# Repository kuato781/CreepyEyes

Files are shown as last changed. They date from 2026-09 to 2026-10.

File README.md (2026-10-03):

# CreepyEyes

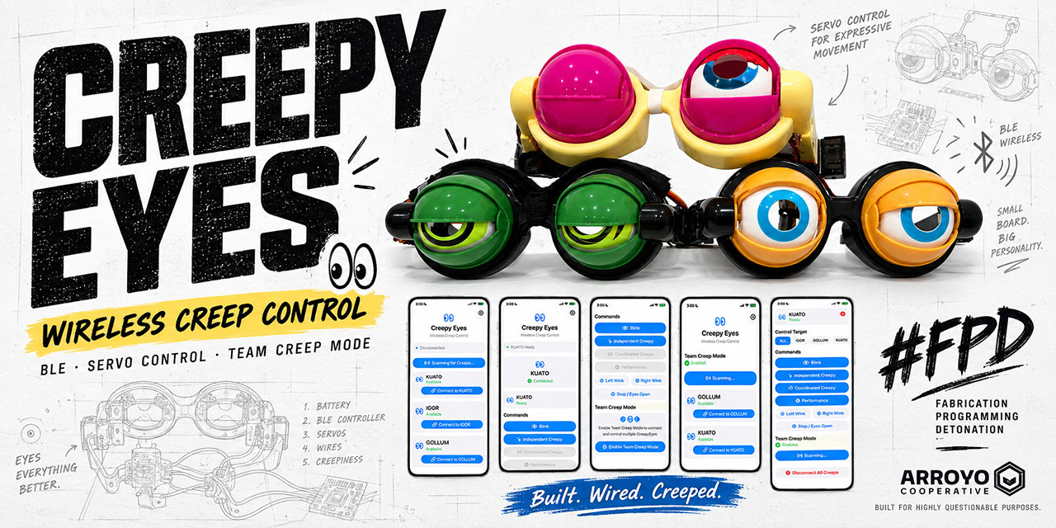
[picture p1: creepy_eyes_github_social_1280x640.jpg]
CreepyEyes


Native iPhone BLE control for servo-driven **Creepy Eyes** glasses.

Built by Arroyo Cooperative for highly questionable purposes. 👀

CreepyEyes combines:

- a native SwiftUI iPhone app
- BLE-connected Seeed Studio XIAO ESP32-C3 controllers
- independently servo-driven eyelids
- per-creep calibration
- single-device and multi-device control
- synchronized pseudo-random movement
- app-orchestrated Performance mode
- a compact wearable hardware build

## Current status

The app is functionally complete through **V3 Team Creep Mode**.

Named Creeps:

- `KUATO`
- `IGOR`
- `GOLLUM`
- `FESTER`
- `LURCH`

The fleet is being standardized on the newer compact hardware architecture documented in [hardware/README.md](hardware/README.md): smaller sub-micro servos, direct-solder servo wiring, formed heat-shrink loom, and the improved ball-bearing linkage clamp.

The compact hardware revision is a substantial packaging cleanup over the original build:

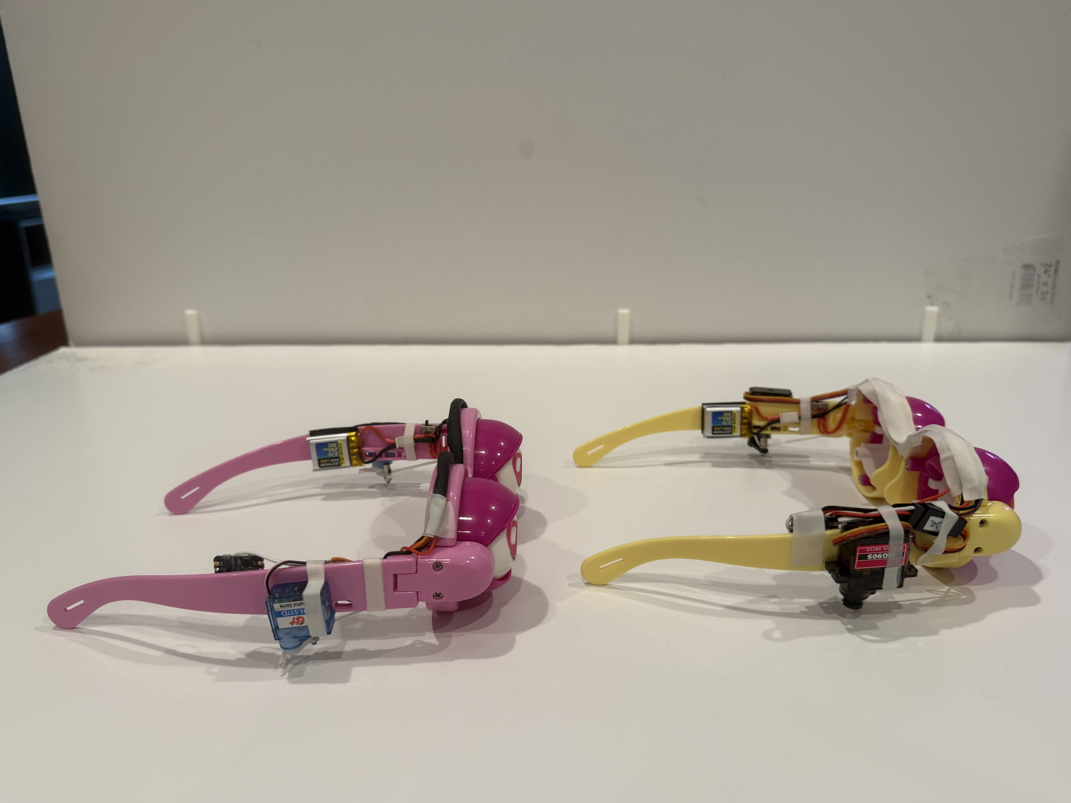
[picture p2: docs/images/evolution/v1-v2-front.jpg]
CreepyEyes hardware evolution


Additional comparison views are available in [`docs/images/evolution/`](docs/images/evolution/), and a short fleet demo is in [`CreepsInMotion.mp4`](docs/images/media/CreepsInMotion.mp4).

## What the app does

The iPhone app:

- scans for nearby CreepyEyes devices
- connects securely over BLE
- displays each creep by its advertised name
- controls one creep by default
- enables multi-device control through **Team Creep Mode**
- stores motion settings locally on the iPhone
- routes commands to one creep or the whole connected fleet
- generates shared seeds for Coordinated Creepy behavior
- orchestrates Performance mode
- safely stops Creeps before disconnecting

Supported behaviors:

- **Blink**
- **Left Wink**
- **Right Wink**
- **Independent Creepy**
- **Coordinated Creepy**
- **Performance**
- **Stop / Eyes Open**

## Team Creep Mode

The app intentionally starts as a simple single-Creep controller.

After one Creep is connected, the user can explicitly enable **Team Creep Mode** for that app session. That reveals `Scan for More Creeps` and allows multiple hardware units to be connected.

With multiple Creeps connected, the app can target:

- `ALL`
- any individual connected creep

Fleet-only behaviors such as Coordinated Creepy and Performance become available when multiple Creeps are connected and `ALL` is selected.

Team Creep Mode is session-only and does not use a password, subscription, license key, or in-app purchase.

## Independent Creepy

Each creep generates its own random movement sequence and speed range, producing intentionally uncoordinated motion across the fleet.

## Coordinated Creepy

The iPhone generates one random seed and sends the same seed and behavior parameters to participating Creeps.

The firmware uses a deterministic pseudo-random generator, so Creeps receiving the same seed follow the same action/speed sequence.

## Performance mode

Performance is orchestrated by the iPhone app rather than hard-coded into the firmware.

Default sequence:

```text
Left Wink
→ Right Wink
→ Blink
→ Independent Creepy
→ Coordinated Creepy
```

The first four phases use the configurable Performance duration. Coordinated Creepy remains active until another command is sent.

`Stop / Eyes Open` interrupts the sequence immediately.

## Factory defaults

```text
Wink Interval               3.0 sec
Wink Speed                  1.0x
Blink Interval              3.0 sec
Blink Speed                 1.0x
Creepy Transition Interval  1.0 sec
Creepy Minimum Speed        0.5x
Creepy Maximum Speed        1.5x
Performance Action Duration 10 sec
```

## BLE protocol

Service UUID:

```text
4fafc201-1fb5-459e-8fcc-c5c9c331914b
```

Characteristic UUID:

```text
beb5483e-36e1-4688-b7f5-ea07361b26a8
```

Commands:

```text
L:<speed>
R:<speed>
B:<transition interval>:<speed>
I:<transition interval>:<minimum speed>:<maximum speed>
C:<transition interval>:<minimum speed>:<maximum speed>:<seed>
S
```

Where:

- `L` = one Left Wink
- `R` = one Right Wink
- `B` = repeating Blink
- `I` = Independent Creepy
- `C` = Coordinated Creepy
- `S` = Stop / Eyes Open

## Hardware orientation convention

**LEFT and RIGHT are defined from the wearer's perspective.**

```text
D4 = wearer's LEFT eye
D5 = wearer's RIGHT eye
```

This convention is used in current firmware, calibration, wiring, and build documentation.

## Hardware build

The current preferred hardware build is documented here:

- [Hardware build guide](hardware/README.md)
- [BOM and tools](hardware/BOM.md)
- [Textual wiring reference](hardware/WIRING.md)

The repository also includes the glasses assembly/calibration fixture and the current 3-slot sliding-lid travel/storage case:

```text
stl-bambu-3mf/
├── creepy-glass-holder.3mf
├── creepy-glass-holder.stl
├── CreepyEyes-3Slot-Box.3mf
├── CreepyEyes_3Slot_Box_BASE_70mm.stl
├── CreepyEyes_3Slot_Box_LID_70mm.stl
├── CreepyEyes_Lid_Overlay_NORMAL.svg
└── CreepyEyes_Lid_Overlay_MIRRORED.svg
```

The case holds three folded Creeps in separate bays and uses the CreepyEyes SVG as a merged lid overlay:

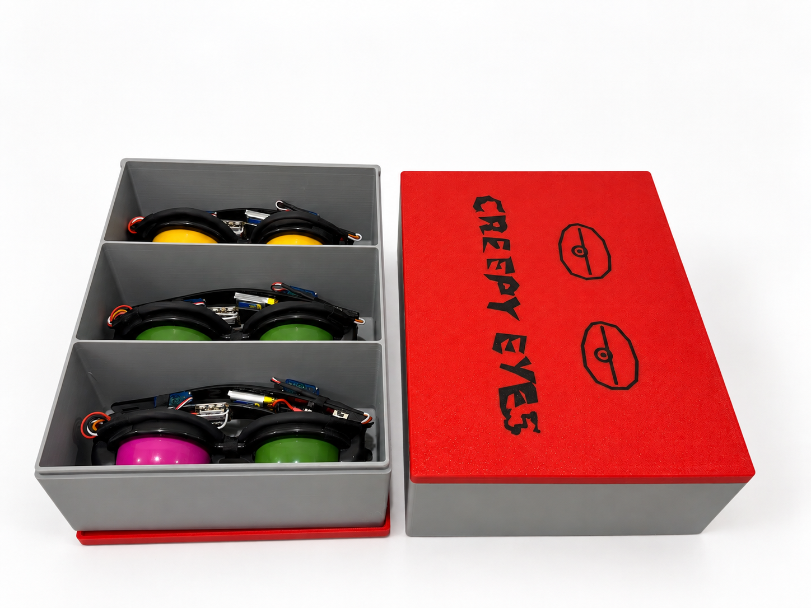
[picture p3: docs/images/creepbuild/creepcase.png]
CreepyEyes 3-slot travel case


## Firmware

The firmware lives under:

```text
firmware/
├── README.md
├── CreepyEyes/
│   ├── CreepyEyes.ino
│   └── secrets.example.h
└── CreepyEyesCalibration/
    └── CreepyEyesCalibration.ino
```

See [firmware/README.md](firmware/README.md) for Arduino setup, calibration, flashing, BLE protocol, and local secrets.

## Local secrets

Production firmware uses a local `secrets.h`:

```cpp
#pragma once
#define CREEP_NAME "KUATO"
#define FLEET_PASSCODE 123456
```

The real fleet passcode must remain local. `secrets.h` is excluded by `.gitignore`; only `secrets.example.h` belongs in source control.

## iPhone app architecture

### `BLEManager.swift`

Owns scanning, connections, characteristic discovery, per-device command channels, command transmission, safe disconnect, and multi-creep BLE state.

### `ContentView.swift`

Owns UI and orchestration: Team Creep Mode, target selection, motion settings, Performance sequencing, and Coordinated Creepy seed generation.

The app sends semantic behavior commands rather than raw servo positions.

## Design philosophy

Firmware owns:

- servo positions and calibration
- motion timing and interpolation
- blink/wink/Creepy behaviors
- safe stop behavior

The iPhone app owns:

- user settings
- connection/target selection
- Team Creep Mode
- fleet orchestration
- Performance sequencing
- coordinated seed generation

## License and disclaimer

See [LICENSE](LICENSE) and [DISCLAIMER.md](DISCLAIMER.md).

CreepyEyes is a hobbyist wearable-electronics project involving LiPo batteries, custom wiring, moving mechanisms, and modified novelty glasses. Build and use it accordingly.

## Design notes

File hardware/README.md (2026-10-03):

# CreepyEyes Hardware Build

This is the current hardware build guide for CreepyEyes.

It reflects the newer compact build developed while assembling FESTER: smaller sub-micro servos, direct-soldered servo wiring, a formed heat-shrink wiring loom, and a 2.5 mm ball-bearing clamp inside the pushrod connector.

> [!WARNING]
> This is not a beginner electronics project. You should already be comfortable with RC servos, small-electronics soldering and wire splicing, multimeter use, LiPo battery handling, flashing firmware to a microcontroller, and basic small-model modification and mechanical fitment.

The exact brands linked in [BOM.md](BOM.md) are what were used during development. Equivalent parts and tools are fine unless a dimension or electrical requirement is specifically called out.

## Build architecture

Each pair of glasses uses:

- 2 sub-micro servos driving the original eyelid mechanisms
- Seeed Studio XIAO ESP32-C3
- 1S 3.7 V 250 mAh LiPo
- DC-DC boost converter configured for approximately 5 V servo power
- 470 µF / 10 V capacitor across the boosted servo rail
- physical power switch
- BT2.0 battery connection
- direct-soldered servo wiring
- heat-shrink-formed loom routed across the frame
- pushrod/linkage connectors clamping the original nylon pull string

The controller and boost board are distributed along the temples rather than stacked.

## Orientation convention

**LEFT and RIGHT are now defined from the wearer's perspective.**

```text
Wearer's LEFT eye  -> D4
Wearer's RIGHT eye -> D5
```

That convention is used in the calibration sketch, production firmware, wiring documentation, and app behavior.

## Before touching electronics

Mechanically inspect the donor glasses first.

Both eyelids should open and close freely before servo installation. If one eye drags or does not fully open, fix or replace the mechanical eye assembly before calibration. A sticky donor mechanism can otherwise look like a servo, linkage, or firmware problem later.

Also test both servos on a servo tester before installing them.

## Servo preparation

The compact build uses GH-S37D-class sub-micro servos rather than the larger MG90S-style servos used in earlier builds.

The smaller servos reduce the side profile significantly and already use thin lead wire that works well with the direct-solder harness.

Optional cleanup:

- trim unused servo mounting ears to reduce bulk
- clean the cut edge carefully without cutting into the case seam

### Servo arm and linkage connector

The supplied servo arms have enough material for the existing pushrod connector.

1. Choose an arm long enough to provide easy access to the connector set screw while still clearing the frame.
2. Enlarge the servo-arm hole to approximately **2.15 mm** so the connector's smooth shoulder can rotate freely.
3. Enlarge the connector's nylon-cord hole to approximately **2 mm** as needed. A diamond Dremel bit works well on the hardened connector material; use high tool speed with low feed pressure.
4. Use the connector nut without a washer.
5. Apply only a small amount of green Loctite to the first 3-5 screw threads. Do not flood Loctite onto the plastic servo arm.
6. Tighten only enough to retain the connector while allowing the smooth shoulder to rotate freely.

The goal is **free rotation and clearance**, not simply making every hole larger.

## Nylon pull-string clamp: current method

The connector's 3 mm set screw does not reach far enough to clamp the thin nylon pull string by itself.

An earlier build used a short piece of 3D-printer filament as a spacer. That worked, but depending on how the filament slug landed, it could damage or cut the nylon string.

The current method uses a **2.5 mm steel ball bearing** inside the connector under the set screw.

The ball:

- fits the connector cleanly
- allows the set screw to clamp the nylon securely
- creates a smooth, repeatable contact surface
- did not leave visible bite marks on the nylon during destructive/reassembly testing

This supersedes the filament-slug method.

## Servo mounting

The working geometry is:

- servos on the outside of the temple frame
- output gear facing rearward
- outer edge aligned near the former stock string-guide edge
- servo body approximately 2 mm below the bottom of the frame

Use servo tape for initial positioning and mechanical testing before committing the final attachment.

Center each servo with a tester before installing the horn. Install the arm near 90 degrees inward and tension the nylon so the eyelid is roughly half closed at servo center. Final endpoints are established later with the calibration sketch.

### Build photos

**Servo installation / fixture setup**

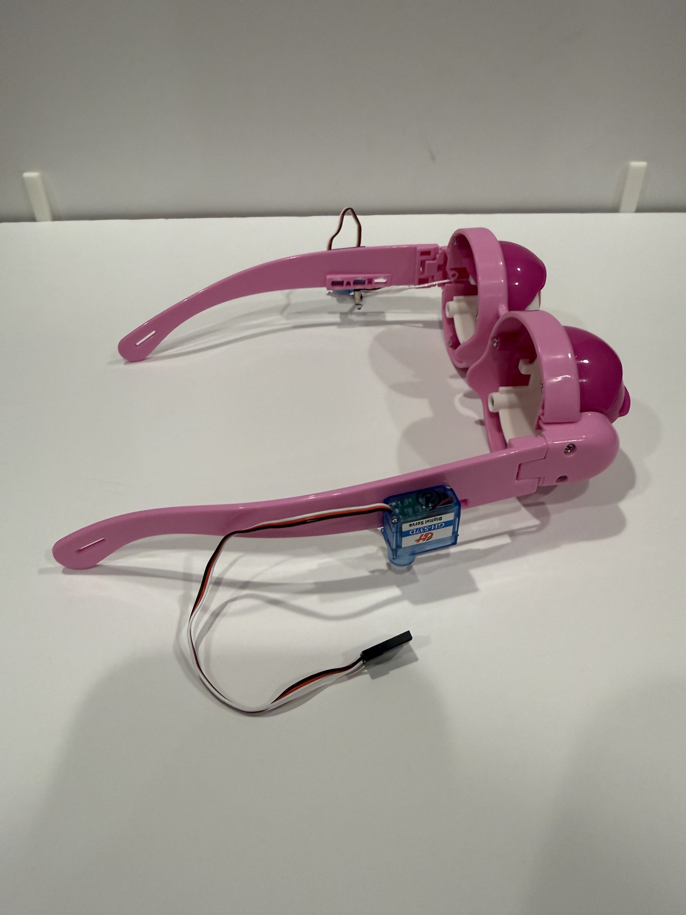
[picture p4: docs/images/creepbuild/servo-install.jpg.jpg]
Servo installation


**Assembly held in the printed fixture**

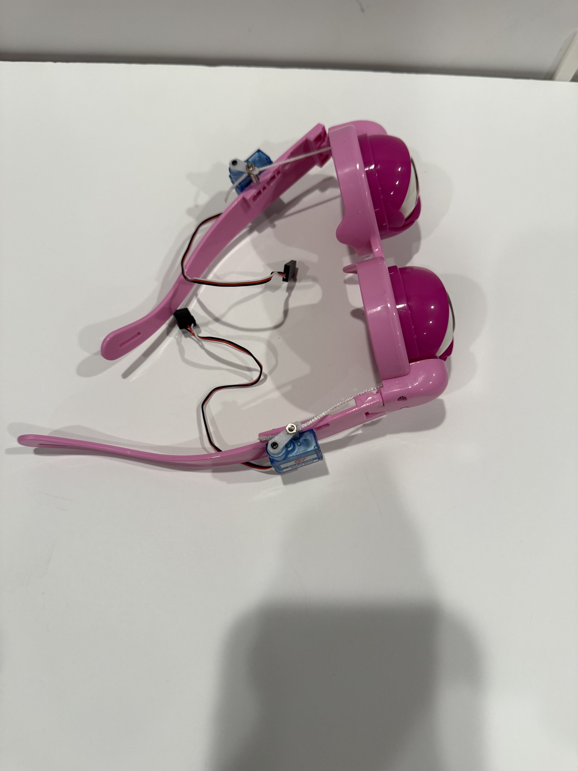
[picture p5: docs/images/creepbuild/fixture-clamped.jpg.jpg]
Fixture clamped


**Finished compact build — front**

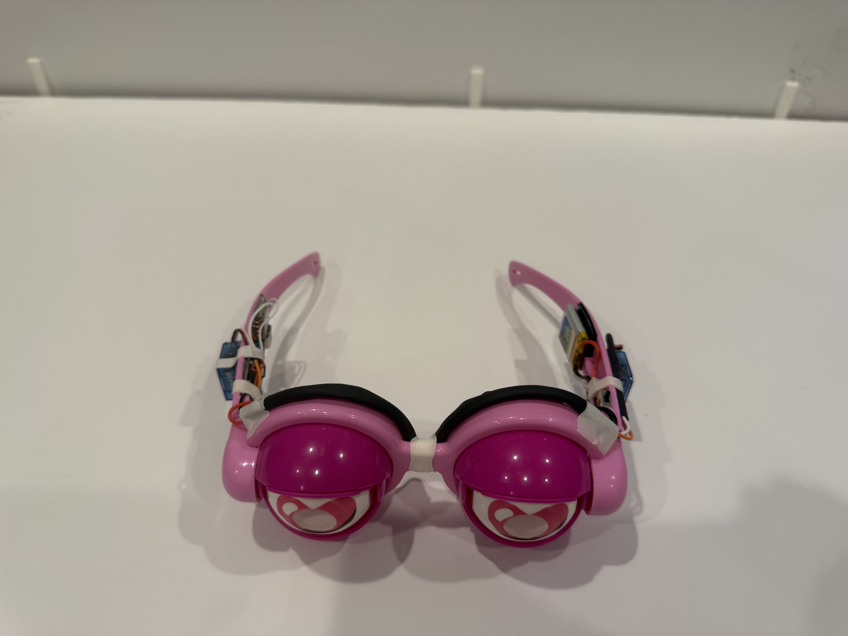
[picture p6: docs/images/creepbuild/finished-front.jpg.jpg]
Finished compact build front


**Finished compact build — side**

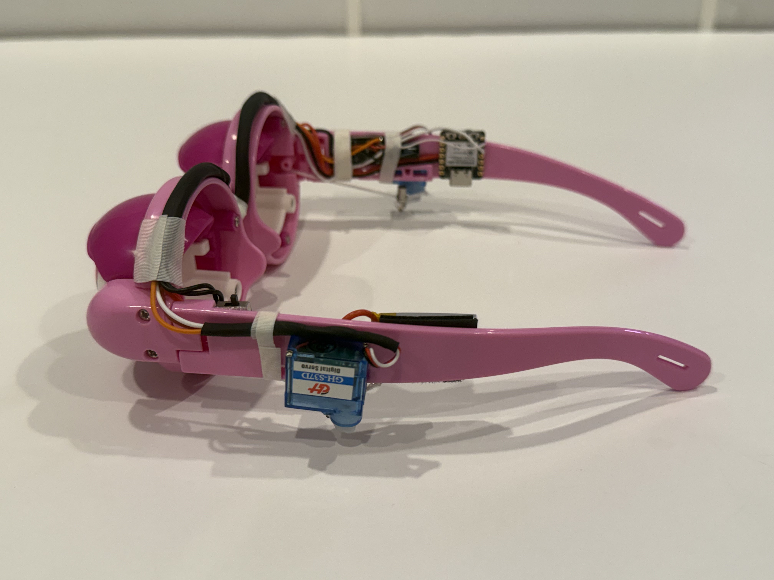
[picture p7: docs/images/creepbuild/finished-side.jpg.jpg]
Finished compact build side


## Battery and switch

The current battery is a 1S 3.7 V 250 mAh LiPo with a BT2.0 connector.

Battery leads were trimmed to about **15 mm** on the compact build.

Mount the battery as far forward as practical with removable hook-and-loop attachment. The battery remains replaceable rather than permanently glued to the glasses.

Preferred switch convention:

```text
forward  = ON
backward = OFF
```

Mount the switch as far forward and high on the lens/frame area as practical without interfering with folding or wearing the glasses.

Shoe Goo works well for permanent component attachment. Clamp parts while curing. Initial handling can happen after a couple of hours, but allow roughly 24-48 hours for a full cure before treating the bond as finished.

## Direct-solder servo harness

The compact build removes the bulky Futaba-style servo connectors entirely.

The servo leads are cut and hard-soldered into the harness. This is reasonable here because the servos are lightly loaded and a failed servo can still be serviced at the documented splice location.

A useful stagger for the three servo conductors is:

```text
black  25 mm
red    35 mm
white  45 mm
```

Staggering the joints keeps the loom from developing one large rigid bulge.

Current color mapping at the servo splice:

```text
servo black -> harness brown / ground
servo red   -> harness orange / +5 V servo rail
servo white -> harness white / signal
```

Individual joints are insulated and the harness is then bundled for routing.

## Formed heat-shrink loom

The cross-frame wiring is placed inside heat shrink, warmed, and **formed around the glasses while still warm**. Once cool, the loom naturally holds the frame shape.

This reduces the amount of tape needed: a few retention points can hold a pre-shaped loom instead of taping loose wires along the entire frame.

Current working lengths:

```text
1/8 in heat shrink:  about 50 mm per servo-lead section
3/16 in heat shrink: about 170 mm for the seven-wire main bundle
```

## Wiring

The old graphical/PDF wiring diagram is obsolete. The canonical wiring description is now textual in [WIRING.md](WIRING.md).

Do not power the servos from the XIAO 3V3 rail.

The boost converter supplies the servo rail; the XIAO and servo system share ground.

## Boost converter

The compact build uses the same small DC-DC boost board as earlier Creeps.

Configure it for approximately **5 V output** by removing the board's factory configuration jumpers/pads used for the alternate voltage presets.

Before connecting servos:

1. connect battery/input wiring
2. switch the glasses on
3. confirm the boost board's power LED
4. measure the output with a multimeter
5. verify approximately 5 V at the servo rail

Only after that should the servos be connected.

Install the **470 µF / 10 V capacitor across boost OUT+ and OUT-**, observing polarity. Trim its leads short.

The capacitor is on the 5 V servo rail, not on the XIAO battery pads.

## XIAO controller

Mount the XIAO with:

- USB connector accessible
- board parallel to the bottom of the frame
- enough clearance for servo arm/linkage movement

Signal convention:

```text
D4 -> wearer's LEFT servo signal
D5 -> wearer's RIGHT servo signal
```

Power leads can be soldered to the underside while servo signals enter from the top, keeping the package compact.

## Power-on checks

Before final assembly:

- switch OFF: no battery voltage should appear on the switched positive distribution
- switch ON: battery voltage should be present at the XIAO battery input and boost input
- boost output: approximately 5 V
- XIAO logic rail: approximately 3.3 V where expected
- common ground continuity: controller and servo system share ground

Disconnect the battery before trimming any exposed test points or conductors.

## Calibration and firmware

Do not permanently finish the wiring before calibration and full-power servo testing.

Recommended order:

1. mechanically inspect donor glasses
2. test servos with servo tester
3. mount servos and linkage
4. complete power wiring
5. verify battery and boost voltages
6. flash `CreepyEyesCalibration.ino`
7. determine LEFT OPEN / LEFT CLOSED / RIGHT OPEN / RIGHT CLOSED
8. add or update the calibration block in production firmware
9. flash `CreepyEyes.ino`
10. test BLE behavior
11. perform a full battery-powered servo test
12. finish loom routing and permanent attachment

USB power can run the XIAO and BLE logic, but the normal 5 V servo rail depends on the battery/boost system. A final test therefore needs the physical power switch ON and normal battery power.

See [../firmware/README.md](../firmware/README.md) for firmware and calibration details.

## Hardware evolution: V1 vs V2

The newer hardware architecture is primarily a packaging and serviceability refinement:

- smaller GH-S37D-class servos replace larger MG90S-style servos
- servo connectors are removed in favor of staggered direct-solder joints
- factory thin servo wire is retained where useful
- the cross-frame wiring becomes a formed heat-shrink loom
- the 2.5 mm ball-bearing clamp replaces the filament spacer
- component placement is cleaner and closer to the temple profile

### Real-world comparison photos

These are the actual compact-build / earlier-build comparison shots used during development.

**Front**

V1 vs V2 front

**Side profile**

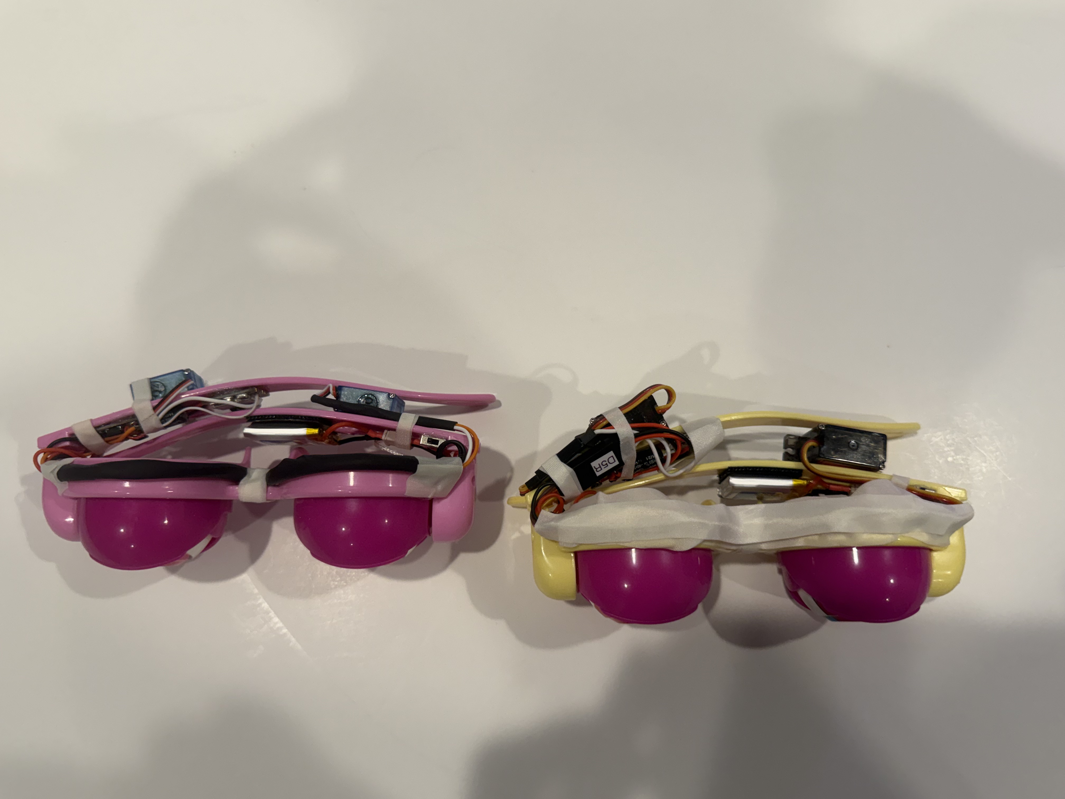
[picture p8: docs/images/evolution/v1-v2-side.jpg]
V1 vs V2 side


**Top / wiring profile**

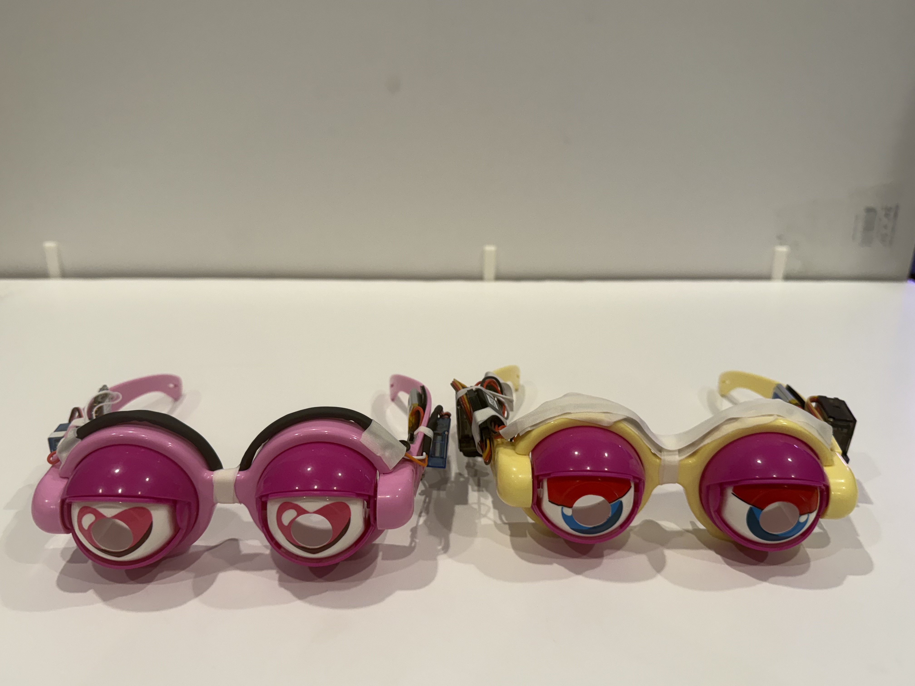
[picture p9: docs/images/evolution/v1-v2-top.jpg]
V1 vs V2 top


**Folded / packed profile**

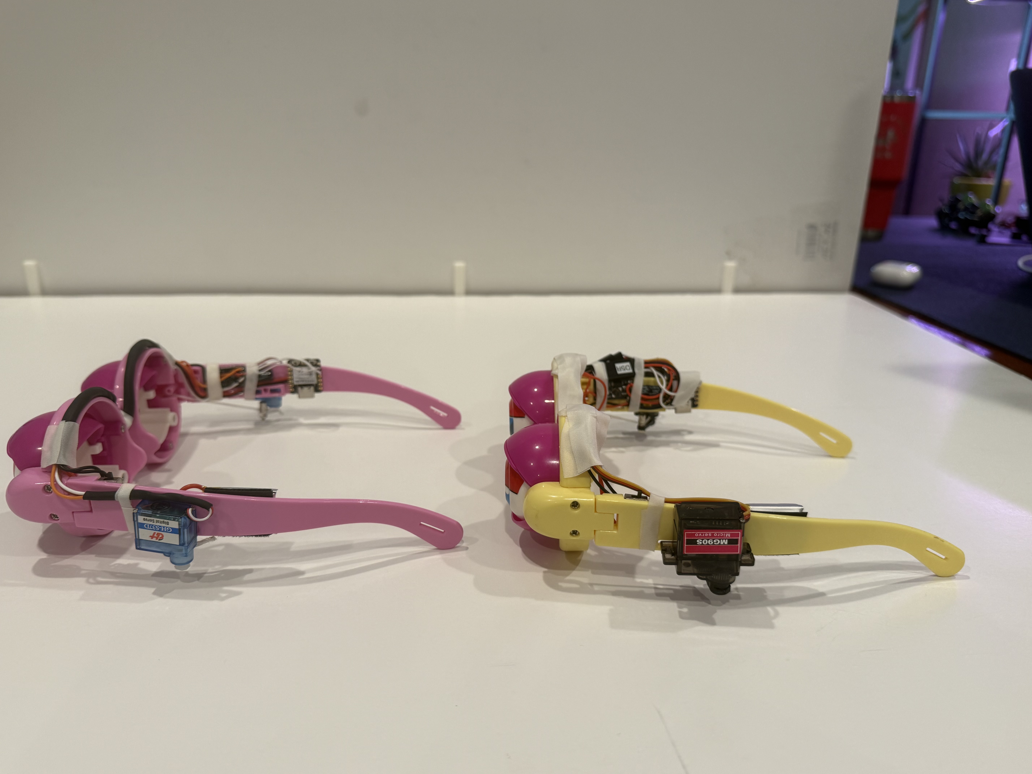
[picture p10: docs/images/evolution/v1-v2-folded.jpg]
V1 vs V2 folded


A short fleet demo is also available here:

[CreepsInMotion.mp4](../docs/images/media/CreepsInMotion.mp4)

The older architecture still works; the compact build is simply the preferred pattern going forward.

## Lessons learned

A few build failures materially improved the design:

- **Check the donor eye mechanism first.** A sticky eyelid can waste time debugging electronics that are not actually at fault.
- **Continuity alone does not prove a tiny XIAO pad joint is good.** If one signal behaves strangely, reflow the solder joint before condemning the GPIO.
- **Do not use the old filament slug as the nylon clamp.** The 2.5 mm ball-bearing spacer is more repeatable and does not damage the cord in current testing.
- **Test before final Shoe Goo/tape.** Calibration, BLE, and full-power motion should all work before the packaging becomes difficult to service.
- **Form the loom while the heat shrink is warm.** The cooled loom then follows the frame naturally and requires much less tape.

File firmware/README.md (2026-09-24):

# CreepyEyes Firmware

Firmware for the servo-driven CreepyEyes glasses.

This directory contains:

- shared production firmware for the Creep Fleet
- a calibration sketch used when building or servicing an individual creep

```text
firmware/
├── CreepyEyes/
│   ├── CreepyEyes.ino
│   └── secrets.example.h
├── CreepyEyesCalibration/
│   └── CreepyEyesCalibration.ino
└── README.md
```

## Hardware mapping

Current controller: **Seeed Studio XIAO ESP32-C3**.

**LEFT and RIGHT are defined from the wearer's perspective.**

```text
D4 = wearer's LEFT servo
D5 = wearer's RIGHT servo
```

The servos are powered from the separate boosted ~5 V rail, not the XIAO 3V3 pin. Controller and servo rail share ground.

For full hardware wiring see [../hardware/WIRING.md](../hardware/WIRING.md).

## Shared production firmware

The same `CreepyEyes.ino` is used across the fleet.

Per-creep differences are selected using `CREEP_NAME` and calibration blocks inside the firmware.

Named Creeps currently represented in the firmware:

- KUATO
- IGOR
- GOLLUM
- FESTER
- LURCH

## Arduino environment

Current development environment:

- Arduino IDE
- `esp32 by Espressif Systems`
- board: `XIAO_ESP32C3`
- `ESP32Servo`
- Serial Monitor: `115200`

## Calibration

Before flashing production firmware onto a newly built creep, measure its servo endpoints with:

```text
firmware/CreepyEyesCalibration/CreepyEyesCalibration.ino
```

The sketch starts both servos at 90 and accepts:

```text
L = select LEFT servo
R = select RIGHT servo
+ = increase selected position by 1
- = decrease selected position by 1
P = print current positions
```

The four values required for each physical creep are:

```text
LEFT_OPEN
LEFT_CLOSED
RIGHT_OPEN
RIGHT_CLOSED
```

Recommended process:

1. mechanically assemble and inspect the glasses
2. flash the calibration sketch
3. open Serial Monitor at 115200
4. select LEFT and determine safe OPEN/CLOSED endpoints
5. select RIGHT and determine safe OPEN/CLOSED endpoints
6. record all four values
7. add/update the creep's calibration block in `CreepyEyes.ino`
8. set the matching local `CREEP_NAME`
9. flash production firmware
10. test BLE and full battery-powered motion

Do not keep driving a servo after the linkage reaches its safe mechanical endpoint.

## BLE protocol

All Creeps share the same BLE service and characteristic UUIDs and advertise using their configured `CREEP_NAME`.

```text
L:<speed>
R:<speed>
B:<transition interval>:<speed>
I:<transition interval>:<minimum speed>:<maximum speed>
C:<transition interval>:<minimum speed>:<maximum speed>:<seed>
S
```

Defaults:

```text
L = L:1.00
R = R:1.00
B = B:3.00:1.00
I = I:1.00:0.50:1.50
C = C:1.00:0.50:1.50:<default seed>
```

`L` and `R` are one-shot winks. `B` repeats blink behavior. `I` runs Independent Creepy. `C` uses a deterministic shared pseudo-random seed for Coordinated Creepy. `S` stops the active mode and opens the eyes.

The production firmware accepts the same parser from BLE and the Serial Monitor, so commands can be tested from either path.

## Performance mode

Performance is implemented in the iPhone app, not as a firmware opcode.

The app sequences Left Wink, Right Wink, Blink, Independent Creepy, then Coordinated Creepy. Firmware simply executes the semantic commands it receives.

## Local secrets

Production firmware uses a local `secrets.h` containing the creep identity and fleet BLE passcode.

Start from:

```text
firmware/CreepyEyes/secrets.example.h
```

Example local file:

```cpp
#pragma once
#define CREEP_NAME "KUATO"
#define FLEET_PASSCODE 123456
```

`secrets.h` must not be committed. The real passcode should remain local and should be rotated if ever exposed in repository history.

## Production flashing workflow

1. calibrate with `CreepyEyesCalibration.ino`
2. record endpoints
3. update/verify the creep calibration block in `CreepyEyes.ino`
4. set the correct local `CREEP_NAME`
5. select `XIAO_ESP32C3`
6. compile and upload production firmware
7. open Serial Monitor at 115200
8. confirm creep identity and calibration
9. test BLE commands
10. perform a full-power test with the normal battery/boost servo rail
11. finish permanent wiring/packaging only after the test passes

USB can power the XIAO/BLE logic, but it does not represent the normal boosted servo-power path. Final motion testing therefore needs the glasses' battery power switched on.

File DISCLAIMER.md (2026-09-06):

# Disclaimer

CreepyEyes is a hobbyist / maker project and is provided **as-is**, without
warranty of any kind.

The source code, firmware, electrical information, hardware configuration,
component suggestions, assembly instructions, photographs, graphics, and
other materials in this repository are intended for experimentation and
personal entertainment.

This project is not a professionally engineered, certified, medically
approved, or safety-rated wearable device.

## Electronics and Wearable Use

CreepyEyes places hobby electronics, wiring, servos, batteries, and mechanical
components on or near the user's head and face.

You are solely responsible for determining whether your completed device is
safe and suitable to wear.

Before wearing or allowing another person to wear a CreepyEyes device:

- inspect all wiring for shorts, damaged insulation, exposed conductors, or
  loose solder joints;
- verify that circuit boards, connectors, switches, batteries, and other
  components are securely mounted;
- ensure that no sharp edges, fasteners, solder joints, wires, or mechanical
  parts can contact the user's eyes, face, skin, or hair;
- confirm that moving servo mechanisms cannot pinch, snag, strike, or trap
  the wearer;
- verify that the glasses can be removed immediately if necessary;
- test the completed device off-body before wearing it;
- stop using the device immediately if any component becomes unusually hot,
  damaged, loose, swollen, or behaves unexpectedly.

Do not wear or operate the device while driving, cycling, operating machinery,
or performing any activity where obscured vision, distraction, unexpected
movement, or equipment failure could create a hazard.

## Battery Safety

This project may use lithium-polymer (LiPo) batteries.

LiPo batteries can present fire, burn, electrical, and property-damage risks
if improperly charged, discharged, damaged, shorted, modified, punctured, or
stored.

Use only appropriate batteries and chargers. Follow the battery and charger
manufacturer's instructions and ratings.

Never use a swollen, punctured, overheated, damaged, or otherwise questionable
battery.

The repository owner and contributors do not warrant that any particular
battery, charger, wiring arrangement, boost converter, connector, or power
configuration is safe or suitable for your specific build.

## Electrical and Mechanical Variability

Component tolerances, servo behavior, wiring, soldering, battery condition,
boost-converter settings, mounting methods, glasses construction, and other
factors may differ significantly between builds.

Servo calibration values from one pair of glasses must not be assumed to be
correct for another pair.

Verify servo direction, open and closed endpoints, mechanical travel, current
draw, and physical clearance before normal use.

Do not allow a servo to continuously stall, bind, or force the eye mechanism.

## Bluetooth and Software

The Bluetooth control system and application are provided for convenience and
entertainment.

No representation is made that Bluetooth pairing, authentication, passwords,
device naming, or other security measures in this project provide protection
appropriate for sensitive, confidential, safety-critical, or hostile
environments.

Wireless connections may fail, disconnect, reconnect, experience interference,
or behave differently across devices and operating-system versions.

Do not rely on wireless control as an emergency-stop or safety mechanism.

The application, firmware, operating-system APIs, development tools, and
third-party libraries may change over time and may introduce incompatibilities
or unexpected behavior.

## No Medical or Protective Purpose

CreepyEyes is a novelty / entertainment project.

It is not:

- medical equipment;
- protective eyewear;
- vision-correction equipment;
- safety equipment;
- assistive technology;
- life-support equipment;
- an emergency signaling device.

Do not use it for any purpose where failure could reasonably result in serious
injury, loss of life, or significant property damage.

## Assumption of Risk

By downloading, modifying, building, programming, assembling, wearing,
operating, sharing, or otherwise using materials from this repository, you
accept responsibility for determining whether they are appropriate for your
intended use.

You assume all risks associated with construction and use, including but not
limited to:

- electrical shorts or component failure;
- battery damage, overheating, fire, or burns;
- damaged phones, computers, chargers, electronics, or other equipment;
- eye, face, skin, or other personal injury;
- pinching, snagging, or mechanical injury;
- loss or impairment of vision while wearing the device;
- property damage;
- software or firmware malfunction;
- unintended servo movement;
- wireless connection or security failure;
- any other loss, cost, damage, or consequence resulting from use or misuse.

## Limitation of Liability

To the maximum extent permitted by applicable law, Javier Arroyo, Arroyo
Cooperative LLC, and project contributors will not be liable for any direct,
indirect, incidental, special, consequential, exemplary, or other loss,
damage, cost, injury, or claim arising from the project or from its use,
modification, assembly, distribution, or inability to be used.

## Modifications and Redistribution

If you modify or redistribute this project, clearly identify your changes.

You are responsible for validating your modified version and should preserve
this disclaimer or provide an equivalent notice to downstream users.

## Relationship to the License

This disclaimer supplements the repository's [LICENSE](LICENSE) file and does
not replace or modify its terms.

If there is any conflict, the license controls.

---

Use common sense, verify the build before strapping it to somebody's face,
and remember that this entire project exists because apparently pulling two
strings manually was not complicated enough. :-)

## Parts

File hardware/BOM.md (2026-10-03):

# CreepyEyes BOM and Shop Tools

This is the working buy list for the current compact CreepyEyes hardware build.

Prices below are snapshots from the development build and will change. Exact brands are not mandatory unless a fit or electrical requirement is called out.

## Parts that become part of the glasses

| Item | Current source / notes |
| --- | --- |
| Donor Creepy Eyes glasses | [Amazon](https://www.amazon.com/Crazy-Glasses-Blinking-Eyeball-Adults/dp/B0GT4KL9V3/) — development buy was a 4-pack |
| 2x sub-micro servos | [Amazon](https://www.amazon.com/dp/B0GTPPWXXL) — current compact-build servo; much smaller than earlier MG90S-class units |
| Seeed Studio XIAO ESP32-C3 | [Amazon](https://www.amazon.com/dp/B0DGX3LSC7) |
| 1S 3.7 V 250 mAh LiPo | [Common Sense RC](https://www.commonsenserc.com/product_info.php?products_id=4223) — removable battery |
| DC-DC step-up / boost board | [Amazon](https://www.amazon.com/dp/B0B4TB9QNY) — configure to ~5 V output |
| Pushrod / linkage connectors | [Amazon](https://www.amazon.com/dp/B01EE6W2TW) |
| 2.5 mm steel ball bearings | [Amazon](https://www.amazon.com/dp/B08KTBM74G) — current clamp spacer under the linkage set screw; tested tight with no visible bite marks on the nylon pull string |
| 470 µF / 10 V electrolytic capacitor | [Amazon](https://www.amazon.com/dp/B0C1VBXCQM) — across boost OUT+ / OUT- |
| Small slide switch | [Amazon](https://www.amazon.com/dp/B0G8W9QNBQ) |
| BT2.0 connectors | [Amazon](https://www.amazon.com/dp/B081CFXCH8) |
| 28 AWG hookup wire | red, black, orange, brown, white as used in the current loom |
| 1/8 in heat shrink | about 50 mm per servo-lead section |
| 3/16 in heat shrink | about 170 mm for the seven-wire cross-frame bundle |
| Black cloth tape | [Amazon](https://www.amazon.com/gp/product/B0DQPTC3CD) |
| White cloth tape | [Amazon](https://www.amazon.com/gp/product/B0DQPT1TL5) |
| Shoe Goo | component attachment |
| Hook-and-loop / Velcro | removable battery mounting |
| Nylon pull string | reuses/replaces the stock eyelid pull line as needed |

## Optional / legacy parts

| Item | Notes |
| --- | --- |
| JST-XH 3-pin connectors | [Amazon](https://www.amazon.com/gp/product/B0D3LVLMP9) — experimented with during development; not used in the preferred direct-solder servo architecture |
| Servo Y splitters | Not required by the current direct-solder harness. Equivalent parts may still be useful for bench work. |
| External LiPo charge board | [Amazon](https://www.amazon.com/dp/B0H6JPVCG4) — use only if it matches your battery/charging workflow and you understand 1S LiPo charging requirements |

## Useful tools

These are the tools used during the build. Equivalent tools are fine.

| Tool | Current source / purpose |
| --- | --- |
| Servo tester | Convenient for centering and mechanical checks before firmware; any standard compatible tester is fine |
| Soldering iron with suitable tips | Fine/medium conical tip for XIAO/boost pads; larger tip for power wiring |
| Multimeter | Mandatory for verifying battery, 5 V boost output, and continuity |
| Solder wick | [Amazon](https://www.amazon.com/dp/B0DRN688Q5) — convenient for changing boost-board solder jumpers |
| Modeler clamps | [Amazon](https://www.amazon.com/dp/B081HY1VGB) |
| Forceps | [Amazon](https://www.amazon.com/dp/B08Z1SV28S) |
| Diamond Dremel bits | [Amazon](https://www.amazon.com/dp/B0BVMBK8Q5) — connector/string-hole work |
| Magnetic helping hands | [Omnifixo](https://omnifixo.com/en-us) |
| Double-stick servo tape | [Amazon](https://www.amazon.com/dp/B077QMLM7C) |
| Headband magnifier | [Amazon](https://www.amazon.com/Headband-Magnifier-Head-Mounted-Binocular-Magnification-1-5X/dp/B07M7H3P95/) |
| Sprue/flush cutters | servo-ear trimming and general model work |
| Heat gun / controlled heat source | shrinking and forming the loom |
| Small hex drivers | linkage set screw and small hardware |
| Hobby knife / files | cleanup and fitment |

## Printed fixture

The repository includes a simple glasses holder used during assembly/calibration:

```text
stl-bambu-3mf/
├── creepy-glass-holder.3mf
└── creepy-glass-holder.stl
```

The fixture holds the temples open consistently while soldering, fitting linkages, calibrating, and photographing the build.

## Printed travel / storage case

The repository also includes the current 3-slot sliding-lid case used to carry the Creeps:

```text
stl-bambu-3mf/
├── CreepyEyes-3Slot-Box.3mf
├── CreepyEyes_3Slot_Box_BASE_70mm.stl
├── CreepyEyes_3Slot_Box_LID_70mm.stl
├── CreepyEyes_Lid_Overlay_NORMAL.svg
└── CreepyEyes_Lid_Overlay_MIRRORED.svg
```

The SVG files are intended for a merged lid graphic; the normal and mirrored versions support either face/orientation workflow.

CreepyEyes case

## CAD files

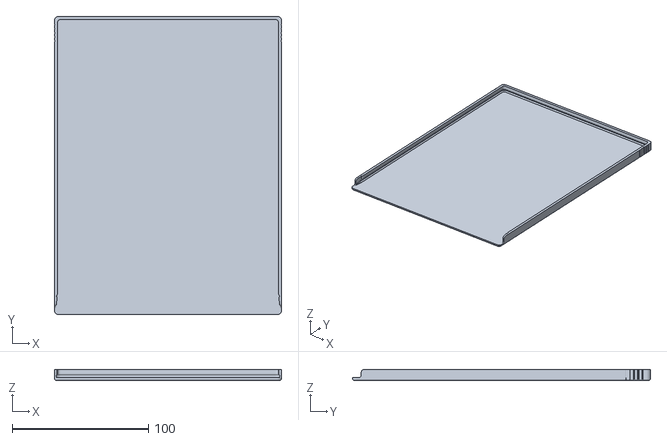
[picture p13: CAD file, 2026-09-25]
stl-bambu-3mf/CreepyEyes_3Slot_Box_LID_70mm.stl
166.8 x 218.8 x 8.00

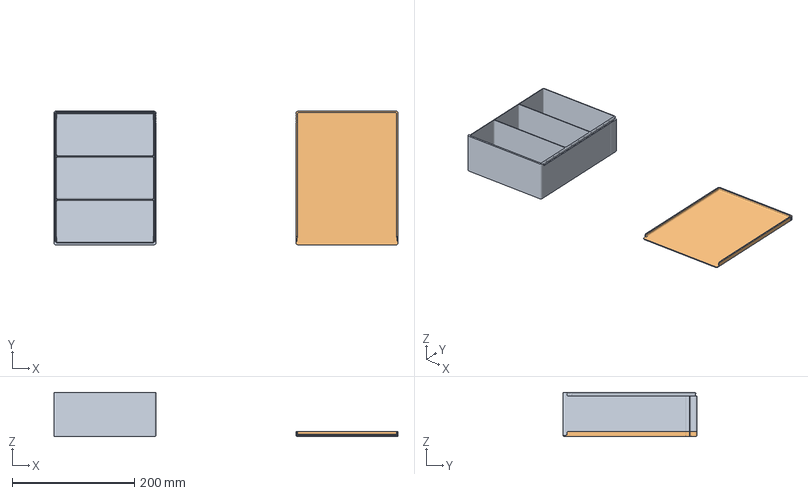
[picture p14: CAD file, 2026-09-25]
stl-bambu-3mf/CreepyEyes-3Slot-Box.3mf
562.8 x 218.8 x 72.0 mm
CreepyEyes_3Slot_Box_BASE_70mm.stl
CreepyEyes_3Slot_Box_LID_70mm.stl

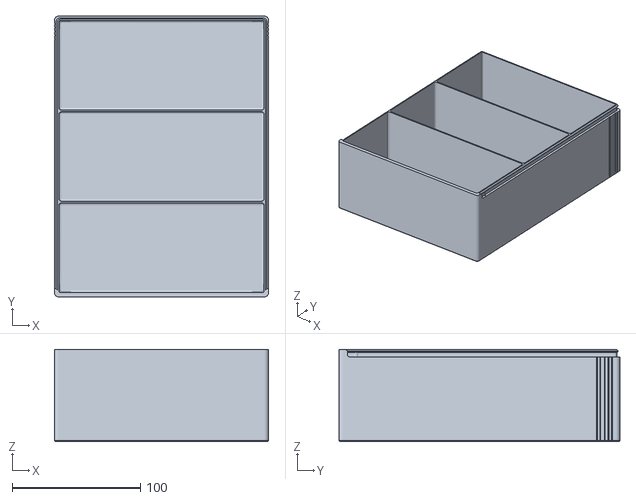
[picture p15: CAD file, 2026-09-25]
stl-bambu-3mf/CreepyEyes_3Slot_Box_BASE_70mm.stl
166.8 x 218.8 x 72.0

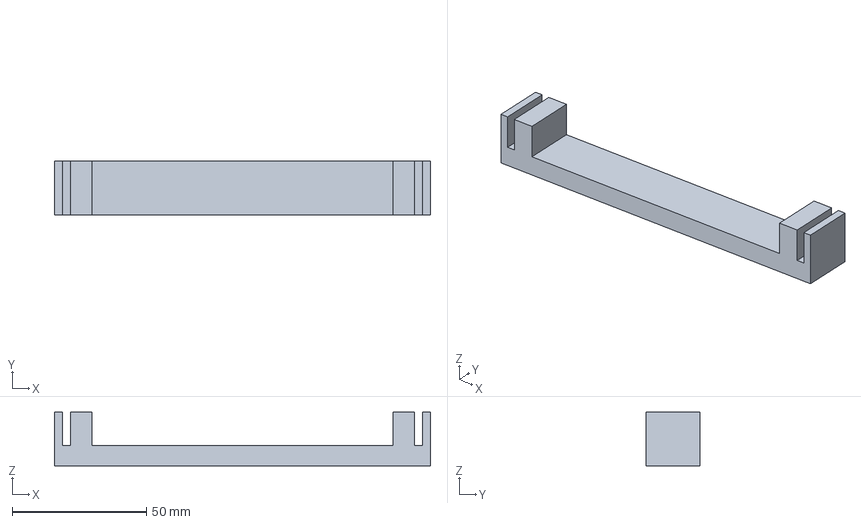
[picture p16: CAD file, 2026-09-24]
stl-bambu-3mf/creepy-glass-holder.3mf
140.0 x 20.0 x 20.0 mm

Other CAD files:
stl-bambu-3mf/creepy-glass-holder.stl

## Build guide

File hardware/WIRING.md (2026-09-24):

# CreepyEyes Wiring — Current Textual Reference

This file replaces the older graphical/PDF wiring diagram.

**LEFT and RIGHT are defined from the wearer's perspective.**

```text
Wearer's LEFT servo signal  -> D4
Wearer's RIGHT servo signal -> D5
```

## Power topology

```text
1S LiPo (+)
    |
    +--> physical switch -->+--> XIAO BAT+
                            |
                            +--> Boost IN+

1S LiPo (-) ----------------+--> XIAO BAT-
                            |
                            +--> Boost IN-

Boost OUT+ (~5 V) ----------+--> LEFT servo +
                            +--> RIGHT servo +

Boost OUT- -----------------+--> LEFT servo ground
                            +--> RIGHT servo ground

470 µF / 10 V capacitor:
    + lead -> Boost OUT+
    - lead -> Boost OUT-
```

The XIAO and servo system therefore share a common ground, but the servos are powered from the boosted ~5 V rail — **not** from the XIAO 3V3 pin.

## Servo signals

```text
Wearer's LEFT servo signal  -> XIAO D4
Wearer's RIGHT servo signal -> XIAO D5
```

## Current wire-color convention

At the direct-solder servo splice:

```text
servo black -> harness brown -> servo ground / Boost OUT-
servo red   -> harness orange -> servo +5 V / Boost OUT+
servo white -> harness white  -> servo signal
```

For the second servo, black/red/white conductors may remain black/red/white where convenient; electrical function matters more than matching colors. Keep the loom documented and verify every conductor before soldering.

## Working cut lengths from the compact build

These are build-specific working lengths, not universal electrical requirements:

```text
Battery leads:                    ~15 mm
Red/black battery -> boost:      ~300 mm
Red/black battery -> controller: ~380 mm
Orange/brown servo power run:    ~300 mm
White servo signal run:          ~380 mm

Servo splice stagger:
  black: ~25 mm
  red:   ~35 mm
  white: ~45 mm
```

Trim only after dry-fitting the actual glasses. Different donor frames or component placement may require different lengths.

## Heat-shrink loom

```text
1/8 in heat shrink:  ~50 mm on servo-lead sections
3/16 in heat shrink: ~170 mm around the seven-wire main bundle
```

Warm the cross-frame shrink tube and form it to the frame while still pliable. Once cool it retains the curve and needs only a few cloth-tape retention points.

## Boost converter setup

The boost board used during development ships configured for a different voltage range/preset. Reconfigure it for approximately **5 V output** by removing the appropriate factory solder jumpers/pads used on this board.

Always confirm actual output with a multimeter before connecting servos.

```text
Expected:
Battery input: ~3.7-4.2 V depending on charge state
Boost output:  ~5 V
```

## Capacitor

Install the 470 µF / 10 V electrolytic capacitor directly across the servo rail:

```text
capacitor + -> Boost OUT+
capacitor - -> Boost OUT-
```

Observe polarity. Keep leads short.

The boost LED may remain lit briefly after switch-off while the capacitor discharges; that is normal for this build.

## Final checks before connecting servos

1. Battery disconnected: inspect for shorts and solder bridges.
2. Switch OFF: verify switched positive is dead.
3. Switch ON: verify battery voltage at XIAO BAT and boost input.
4. Verify boost output is approximately 5 V.
5. Verify controller/servo grounds are common.
6. Connect servos only after the power rails check out.
7. Perform final servo motion testing with normal battery power; USB alone does not represent the completed 5 V servo-power path.

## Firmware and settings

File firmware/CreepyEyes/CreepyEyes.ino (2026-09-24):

#include <ESP32Servo.h>
#include <BLEDevice.h>
#include <BLEUtils.h>
#include <BLEServer.h>
#include <BLESecurity.h>
#include "secrets.h"

Servo leftEye;
Servo rightEye;

// ==================================================
// DEVICE SETTINGS
// ==================================================

const char* DEVICE_NAME = CREEP_NAME;
const uint32_t BLE_PASSCODE = FLEET_PASSCODE;

// LEFT/RIGHT are defined from the WEARER'S perspective.

const int LEFT_SERVO_PIN  = D4;
const int RIGHT_SERVO_PIN = D5;

// ==================================================
// CALIBRATION
//
// Selected automatically from CREEP_NAME.
//
// This prevents accidentally flashing GOLLUM's
// calibration into KUATO, etc.
// ==================================================

int LEFT_OPEN;
int LEFT_CLOSED;

int RIGHT_OPEN;
int RIGHT_CLOSED;

void configureCalibration() {

  String name = DEVICE_NAME;
  name.toUpperCase();

  if (name == "KUATO") {

    LEFT_OPEN    = 135;
    LEFT_CLOSED  = 72;

    RIGHT_OPEN   = 19;
    RIGHT_CLOSED = 99;

    Serial.println("Calibration: KUATO");
  }

  else if (name == "IGOR") {

    LEFT_OPEN    = 119;
    LEFT_CLOSED  = 44;

    RIGHT_OPEN   = 31;
    RIGHT_CLOSED = 104;

    Serial.println("Calibration: IGOR");
  }

  else if (name == "GOLLUM") {

    LEFT_OPEN    = 138;
    LEFT_CLOSED  = 55;

    RIGHT_OPEN   = 60;
    RIGHT_CLOSED = 135;

    Serial.println("Calibration: GOLLUM");
  }

  else if (name == "FESTER") {

    LEFT_OPEN    = 127;
    LEFT_CLOSED  = 67;

    RIGHT_OPEN   = 56;
    RIGHT_CLOSED = 129;

    Serial.println("Calibration: FESTER");
  }

  else if (name == "LURCH") {

    LEFT_OPEN    = 102;
    LEFT_CLOSED  = 35;

    RIGHT_OPEN   = 38;
    RIGHT_CLOSED = 115;

    Serial.println("Calibration: LURCH");
  }

  else {

    // Unknown future creep.
    //
    // KUATO values are used only as a fallback.
    // Add the new creep's calibration above before
    // putting it into production.

    Serial.println();
    Serial.println("********************************");
    Serial.println("WARNING: UNKNOWN CREEP NAME");
    Serial.println("Using KUATO calibration fallback");
    Serial.println("********************************");
    Serial.println();

    LEFT_OPEN    = 135;
    LEFT_CLOSED  = 72;

    RIGHT_OPEN   = 19;
    RIGHT_CLOSED = 99;
  }
}

// ==================================================
// SHARED CREEPY EYES BLE PROTOCOL
// Keep these UUIDs the same on every pair.
// ==================================================

#define SERVICE_UUID        "4fafc201-1fb5-459e-8fcc-c5c9c331914b"
#define CHARACTERISTIC_UUID "beb5483e-36e1-4688-b7f5-ea07361b26a8"

// ==================================================
// V2 FACTORY DEFAULTS
//
// These mirror the iPhone app defaults.
// ==================================================

const float DEFAULT_WINK_SPEED = 1.0;

const float DEFAULT_BLINK_INTERVAL = 3.0;
const float DEFAULT_BLINK_SPEED = 1.0;

const float DEFAULT_CREEPY_INTERVAL = 1.0;
const float DEFAULT_CREEPY_MIN_SPEED = 0.5;
const float DEFAULT_CREEPY_MAX_SPEED = 1.5;

// ==================================================
// MODES
// ==================================================

enum Mode {

  IDLE,

  BLINK_MODE,

  INDEPENDENT_CREEPY_MODE,

  COORDINATED_CREEPY_MODE
};

Mode currentMode = IDLE;

// ==================================================
// MOTION STATES
// ==================================================

enum Motion {

  NONE,

  BOTH_CLOSING,
  BOTH_CLOSED,
  BOTH_OPENING,

  LEFT_CLOSING,
  LEFT_CLOSED_STATE,
  LEFT_OPENING,

  RIGHT_CLOSING,
  RIGHT_CLOSED_STATE,
  RIGHT_OPENING
};

Motion motion = NONE;

unsigned long motionStarted = 0;
unsigned long nextAction = 0;

// ==================================================
// BASE MOTION TIMING
//
// Speed 1.0 = these exact timings.
//
// Speed 2.0 = twice as fast.
// Speed 0.5 = half as fast.
// ==================================================

const unsigned long NORMAL_CLOSE_TIME  = 180;
const unsigned long NORMAL_CLOSED_TIME = 100;
const unsigned long NORMAL_OPEN_TIME   = 240;

const unsigned long RESET_SETTLE_TIME = 120;

unsigned long activeCloseTime  = NORMAL_CLOSE_TIME;
unsigned long activeClosedTime = NORMAL_CLOSED_TIME;
unsigned long activeOpenTime   = NORMAL_OPEN_TIME;

// ==================================================
// ACTIVE MODE SETTINGS
// ==================================================

float activeBlinkInterval = DEFAULT_BLINK_INTERVAL;
float activeBlinkSpeed = DEFAULT_BLINK_SPEED;

float activeCreepyInterval = DEFAULT_CREEPY_INTERVAL;
float activeCreepyMinSpeed = DEFAULT_CREEPY_MIN_SPEED;
float activeCreepyMaxSpeed = DEFAULT_CREEPY_MAX_SPEED;

// Dedicated deterministic random state for
// Coordinated Creepy.
//
// Every creep receiving the same seed produces
// the same actions and speeds in the same order.
uint32_t coordinatedRandomState = 1;

// ==================================================
// CURRENT SERVO POSITION
// ==================================================

int leftCurrent = 0;
int rightCurrent = 0;

// ==================================================
// BLE COMMAND QUEUE
// ==================================================

String pendingBLECommand = "";
bool bleCommandReady = false;

// ==================================================
// GENERAL HELPERS
// ==================================================

float clampFloat(
  float value,
  float minimum,
  float maximum
) {

  if (value < minimum) {
    return minimum;
  }

  if (value > maximum) {
    return maximum;
  }

  return value;
}


int interpolateValue(
  int startValue,
  int endValue,
  unsigned long elapsed,
  unsigned long duration
) {

  if (elapsed >= duration) {
    return endValue;
  }

  float progress =
    (float)elapsed /
    (float)duration;

  return startValue +
         (endValue - startValue) *
         progress;
}


void eyesOpen() {

  leftEye.write(LEFT_OPEN);
  rightEye.write(RIGHT_OPEN);

  leftCurrent  = LEFT_OPEN;
  rightCurrent = RIGHT_OPEN;
}

// ==================================================
// COMMAND PARSING HELPERS
// ==================================================

String commandField(
  const String& command,
  int wantedIndex
) {

  int currentIndex = 0;
  int start = 0;

  for (
    int i = 0;
    i <= command.length();
    i++
  ) {

    if (
      i == command.length()
      ||
      command.charAt(i) == ':'
    ) {

      if (currentIndex == wantedIndex) {

        return command.substring(
          start,
          i
        );
      }

      currentIndex++;
      start = i + 1;
    }
  }

  return "";
}


float commandFloat(
  const String& command,
  int index,
  float defaultValue
) {

  String field =
    commandField(
      command,
      index
    );

  if (field.length() == 0) {
    return defaultValue;
  }

  return field.toFloat();
}


uint32_t commandUInt32(
  const String& command,
  int index,
  uint32_t defaultValue
) {

  String field =
    commandField(
      command,
      index
    );

  if (field.length() == 0) {
    return defaultValue;
  }

  return
    (uint32_t)
    strtoul(
      field.c_str(),
      nullptr,
      10
    );
}

// ==================================================
// SPEED ENGINE
// ==================================================

void setMotionSpeed(
  float speedMultiplier
) {

  speedMultiplier =
    clampFloat(
      speedMultiplier,
      0.20,
      3.00
    );

  activeCloseTime =
    max(
      20UL,
      (unsigned long)(
        NORMAL_CLOSE_TIME /
        speedMultiplier
      )
    );

  activeClosedTime =
    max(
      20UL,
      (unsigned long)(
        NORMAL_CLOSED_TIME /
        speedMultiplier
      )
    );

  activeOpenTime =
    max(
      20UL,
      (unsigned long)(
        NORMAL_OPEN_TIME /
        speedMultiplier
      )
    );
}

// ==================================================
// START MOTIONS
// ==================================================

void startBothBlink() {

  motion = BOTH_CLOSING;
  motionStarted = millis();
}


void startLeftWink() {

  motion = LEFT_CLOSING;
  motionStarted = millis();
}


void startRightWink() {

  motion = RIGHT_CLOSING;
  motionStarted = millis();
}

// ==================================================
// MOTION ENGINE
// ==================================================

void updateMotion() {

  unsigned long now =
    millis();

  unsigned long elapsed =
    now - motionStarted;

  switch (motion) {

    case BOTH_CLOSING:

      leftCurrent =
        interpolateValue(
          LEFT_OPEN,
          LEFT_CLOSED,
          elapsed,
          activeCloseTime
        );

      rightCurrent =
        interpolateValue(
          RIGHT_OPEN,
          RIGHT_CLOSED,
          elapsed,
          activeCloseTime
        );

      leftEye.write(leftCurrent);
      rightEye.write(rightCurrent);

      if (
        elapsed >=
        activeCloseTime
      ) {

        leftEye.write(
          LEFT_CLOSED
        );

        rightEye.write(
          RIGHT_CLOSED
        );

        motion =
          BOTH_CLOSED;

        motionStarted =
          now;
      }

      break;


    case BOTH_CLOSED:

      if (
        elapsed >=
        activeClosedTime
      ) {

        motion =
          BOTH_OPENING;

        motionStarted =
          now;
      }

      break;


    case BOTH_OPENING:

      leftCurrent =
        interpolateValue(
          LEFT_CLOSED,
          LEFT_OPEN,
          elapsed,
          activeOpenTime
        );

      rightCurrent =
        interpolateValue(
          RIGHT_CLOSED,
          RIGHT_OPEN,
          elapsed,
          activeOpenTime
        );

      leftEye.write(
        leftCurrent
      );

      rightEye.write(
        rightCurrent
      );

      if (
        elapsed >=
        activeOpenTime
      ) {

        eyesOpen();

        motion = NONE;
      }

      break;


    case LEFT_CLOSING:

      leftCurrent =
        interpolateValue(
          LEFT_OPEN,
          LEFT_CLOSED,
          elapsed,
          activeCloseTime
        );

      leftEye.write(
        leftCurrent
      );

      if (
        elapsed >=
        activeCloseTime
      ) {

        leftEye.write(
          LEFT_CLOSED
        );

        motion =
          LEFT_CLOSED_STATE;

        motionStarted =
          now;
      }

      break;


    case LEFT_CLOSED_STATE:

      if (
        elapsed >=
        activeClosedTime
      ) {

        motion =
          LEFT_OPENING;

        motionStarted =
          now;
      }

      break;


    case LEFT_OPENING:

      leftCurrent =
        interpolateValue(
          LEFT_CLOSED,
          LEFT_OPEN,
          elapsed,
          activeOpenTime
        );

      leftEye.write(
        leftCurrent
      );

      if (
        elapsed >=
        activeOpenTime
      ) {

        leftEye.write(
          LEFT_OPEN
        );

        leftCurrent =
          LEFT_OPEN;

        motion =
          NONE;
      }

      break;


    case RIGHT_CLOSING:

      rightCurrent =
        interpolateValue(
          RIGHT_OPEN,
          RIGHT_CLOSED,
          elapsed,
          activeCloseTime
        );

      rightEye.write(
        rightCurrent
      );

      if (
        elapsed >=
        activeCloseTime
      ) {

        rightEye.write(
          RIGHT_CLOSED
        );

        motion =
          RIGHT_CLOSED_STATE;

        motionStarted =
          now;
      }

      break;


    case RIGHT_CLOSED_STATE:

      if (
        elapsed >=
        activeClosedTime
      ) {

        motion =
          RIGHT_OPENING;

        motionStarted =
          now;
      }

      break;


    case RIGHT_OPENING:

      rightCurrent =
        interpolateValue(
          RIGHT_CLOSED,
          RIGHT_OPEN,
          elapsed,
          activeOpenTime
        );

      rightEye.write(
        rightCurrent
      );

      if (
        elapsed >=
        activeOpenTime
      ) {

        rightEye.write(
          RIGHT_OPEN
        );

        rightCurrent =
          RIGHT_OPEN;

        motion =
          NONE;
      }

      break;


    case NONE:
      break;
  }
}

// ==================================================
// COORDINATED RANDOM ENGINE
//
// xorshift32 provides a tiny deterministic PRNG.
// Same starting seed = same random sequence.
// ==================================================

uint32_t nextCoordinatedRandom() {

  uint32_t x =
    coordinatedRandomState;

  if (x == 0) {
    x = 0x6D2B79F5;
  }

  x ^= x << 13;
  x ^= x >> 17;
  x ^= x << 5;

  coordinatedRandomState =
    x;

  return x;
}


float coordinatedRandomFloat(
  float minimum,
  float maximum
) {

  uint32_t value =
    nextCoordinatedRandom();

  float normalized =
    (float)value /
    (float)UINT32_MAX;

  return minimum +
         normalized *
         (maximum - minimum);
}


int coordinatedRandomAction() {

  return
    nextCoordinatedRandom() %
    5;
}

// ==================================================
// CREEPY ACTION ENGINE
// ==================================================

void runCreepyAction(
  int action,
  float speed
) {

  setMotionSpeed(speed);

  switch (action) {

    case 0:

      Serial.print(
        "CREEPY: BLINK @ "
      );

      Serial.println(speed);

      startBothBlink();

      break;


    case 1:

      Serial.print(
        "CREEPY: LEFT WINK @ "
      );

      Serial.println(speed);

      startLeftWink();

      break;


    case 2:

      Serial.print(
        "CREEPY: RIGHT WINK @ "
      );

      Serial.println(speed);

      startRightWink();

      break;


    case 3:

      Serial.print(
        "CREEPY: BLINK @ "
      );

      Serial.println(speed);

      startBothBlink();

      break;


    case 4:

      Serial.print(
        "CREEPY: BLINK @ "
      );

      Serial.println(speed);

      startBothBlink();

      break;
  }
}


void runIndependentCreepyAction() {

  int action =
    random(0, 5);

  float speed =
    activeCreepyMinSpeed +
    (
      random(0, 10001) /
      10000.0
    )
    *
    (
      activeCreepyMaxSpeed -
      activeCreepyMinSpeed
    );

  runCreepyAction(
    action,
    speed
  );
}


void runCoordinatedCreepyAction() {

  int action =
    coordinatedRandomAction();

  float speed =
    coordinatedRandomFloat(
      activeCreepyMinSpeed,
      activeCreepyMaxSpeed
    );

  runCreepyAction(
    action,
    speed
  );
}

// ==================================================
// COMMAND HANDLER
// ==================================================

void handleCommand(
  String command
) {

  command.trim();
  command.toUpperCase();

  if (
    command.length() == 0
  ) {
    return;
  }

  Serial.print(
    "COMMAND: "
  );

  Serial.println(
    command
  );

  // Every new command:
  //
  // 1. cancels current mode
  // 2. cancels current motion
  // 3. opens both eyes
  // 4. waits briefly
  // 5. starts new behavior

  currentMode = IDLE;
  motion = NONE;

  eyesOpen();

  delay(
    RESET_SETTLE_TIME
  );

  String opcode =
    commandField(
      command,
      0
    );

  // ==================================================
  // B = BLINK
  //
  // B:<interval>:<speed>
  //
  // B alone still works using defaults.
  // ==================================================

  if (opcode == "B") {

    activeBlinkInterval =
      clampFloat(
        commandFloat(
          command,
          1,
          DEFAULT_BLINK_INTERVAL
        ),
        0.25,
        30.0
      );

    activeBlinkSpeed =
      clampFloat(
        commandFloat(
          command,
          2,
          DEFAULT_BLINK_SPEED
        ),
        0.20,
        3.0
      );

    Serial.print(
      "BLINK MODE interval="
    );

    Serial.print(
      activeBlinkInterval
    );

    Serial.print(
      " speed="
    );

    Serial.println(
      activeBlinkSpeed
    );

    setMotionSpeed(
      activeBlinkSpeed
    );

    currentMode =
      BLINK_MODE;

    nextAction =
      millis();
  }

  // ==================================================
  // I = INDEPENDENT CREEPY
  //
  // I:<interval>:<minSpeed>:<maxSpeed>
  // ==================================================

  else if (opcode == "I") {

    activeCreepyInterval =
      clampFloat(
        commandFloat(
          command,
          1,
          DEFAULT_CREEPY_INTERVAL
        ),
        0.20,
        30.0
      );

    activeCreepyMinSpeed =
      clampFloat(
        commandFloat(
          command,
          2,
          DEFAULT_CREEPY_MIN_SPEED
        ),
        0.20,
        3.0
      );

    activeCreepyMaxSpeed =
      clampFloat(
        commandFloat(
          command,
          3,
          DEFAULT_CREEPY_MAX_SPEED
        ),
        0.20,
        3.0
      );

    if (
      activeCreepyMaxSpeed <
      activeCreepyMinSpeed
    ) {

      float temp =
        activeCreepyMinSpeed;

      activeCreepyMinSpeed =
        activeCreepyMaxSpeed;

      activeCreepyMaxSpeed =
        temp;
    }

    Serial.println(
      "INDEPENDENT CREEPY MODE"
    );

    currentMode =
      INDEPENDENT_CREEPY_MODE;

    nextAction =
      millis();
  }

  // ==================================================
  // C = COORDINATED CREEPY
  //
  // C:<interval>:<minSpeed>:<maxSpeed>:<seed>
  //
  // Every creep gets the same seed from the iPhone.
  // ==================================================

  else if (opcode == "C") {

    activeCreepyInterval =
      clampFloat(
        commandFloat(
          command,
          1,
          DEFAULT_CREEPY_INTERVAL
        ),
        0.20,
        30.0
      );

    activeCreepyMinSpeed =
      clampFloat(
        commandFloat(
          command,
          2,
          DEFAULT_CREEPY_MIN_SPEED
        ),
        0.20,
        3.0
      );

    activeCreepyMaxSpeed =
      clampFloat(
        commandFloat(
          command,
          3,
          DEFAULT_CREEPY_MAX_SPEED
        ),
        0.20,
        3.0
      );

    if (
      activeCreepyMaxSpeed <
      activeCreepyMinSpeed
    ) {

      float temp =
        activeCreepyMinSpeed;

      activeCreepyMinSpeed =
        activeCreepyMaxSpeed;

      activeCreepyMaxSpeed =
        temp;
    }

    coordinatedRandomState =
      commandUInt32(
        command,
        4,
        0x6D2B79F5
      );

    if (
      coordinatedRandomState == 0
    ) {

      coordinatedRandomState =
        0x6D2B79F5;
    }

    Serial.println(
      "COORDINATED CREEPY MODE"
    );

    Serial.print(
      "Seed: "
    );

    Serial.println(
      coordinatedRandomState
    );

    currentMode =
      COORDINATED_CREEPY_MODE;

    nextAction =
      millis();
  }

  // ==================================================
  // L = ONE LEFT WINK
  //
  // L:<speed>
  //
  // Wink interval is NOT used here.
  // It is handled by Performance on the iPhone.
  // ==================================================

  else if (opcode == "L") {

    float speed =
      clampFloat(
        commandFloat(
          command,
          1,
          DEFAULT_WINK_SPEED
        ),
        0.20,
        3.0
      );

    Serial.print(
      "LEFT WINK speed="
    );

    Serial.println(
      speed
    );

    setMotionSpeed(
      speed
    );

    startLeftWink();
  }

  // ==================================================
  // R = ONE RIGHT WINK
  // ==================================================

  else if (opcode == "R") {

    float speed =
      clampFloat(
        commandFloat(
          command,
          1,
          DEFAULT_WINK_SPEED
        ),
        0.20,
        3.0
      );

    Serial.print(
      "RIGHT WINK speed="
    );

    Serial.println(
      speed
    );

    setMotionSpeed(
      speed
    );

    startRightWink();
  }

  // ==================================================
  // S = STOP
  // ==================================================

  else if (opcode == "S") {

    Serial.println(
      "STOP / EYES OPEN"
    );
  }

  // ==================================================
  // RESERVED CALIBRATION COMMANDS
  // ==================================================

  else if (opcode == "SL") {

    Serial.println(
      "SET LEFT CALIBRATION - reserved"
    );
  }

  else if (opcode == "SR") {

    Serial.println(
      "SET RIGHT CALIBRATION - reserved"
    );
  }

  else {

    Serial.print(
      "UNKNOWN COMMAND: "
    );

    Serial.println(
      command
    );
  }
}

// ==================================================
// MODE ENGINE
// ==================================================
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
void loop() {

  // Serial Monitor uses the exact same
  // command parser as BLE.

  if (
    Serial.available()
  ) {

    String command =
      Serial.readStringUntil(
        '\n'
      );

    handleCommand(
      command
    );
  }

  // BLE feeds the same command handler.

  if (
    bleCommandReady
  ) {

    String command =
      pendingBLECommand;

    pendingBLECommand =
      "";

    bleCommandReady =
      false;

    handleCommand(
      command
    );
  }

  updateMotion();
  updateMode();
}

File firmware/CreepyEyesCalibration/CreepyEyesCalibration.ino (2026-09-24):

#include <ESP32Servo.h>

Servo leftEye;
Servo rightEye;

// LEFT/RIGHT are defined from the WEARER'S perspective.
const int LEFT_SERVO_PIN  = D4;
const int RIGHT_SERVO_PIN = D5;

int leftPos  = 90;
int rightPos = 90;

char selectedEye = 'L';

void printStatus() {
  Serial.print("Selected: ");
  Serial.print(selectedEye);

  Serial.print("   Left=");
  Serial.print(leftPos);

  Serial.print("   Right=");
  Serial.println(rightPos);
}

void setup() {
  Serial.begin(115200);

  leftEye.attach(LEFT_SERVO_PIN, 500, 2500);
  rightEye.attach(RIGHT_SERVO_PIN, 500, 2500);

  delay(500);

  leftEye.write(leftPos);
  rightEye.write(rightPos);

  Serial.println();
  Serial.println("=== Creepy Eyes Initial Calibration ===");
  Serial.println("L = select LEFT eye");
  Serial.println("R = select RIGHT eye");
  Serial.println("+ = increase selected servo position by 1");
  Serial.println("- = decrease selected servo position by 1");
  Serial.println("P = print current positions");
  Serial.println();

  printStatus();
}

void loop() {
  if (Serial.available()) {
    char c = Serial.read();

    if (c == 'L' || c == 'l') {
      selectedEye = 'L';
      Serial.println("LEFT selected");
    }

    else if (c == 'R' || c == 'r') {
      selectedEye = 'R';
      Serial.println("RIGHT selected");
    }

    else if (c == '+') {
      if (selectedEye == 'L') {
        leftPos++;
        leftEye.write(leftPos);
      } else {
        rightPos++;
        rightEye.write(rightPos);
      }

      printStatus();
    }

    else if (c == '-') {
      if (selectedEye == 'L') {
        leftPos--;
        leftEye.write(leftPos);
      } else {
        rightPos--;
        rightEye.write(rightPos);
      }

      printStatus();
    }

    else if (c == 'P' || c == 'p') {
      printStatus();
    }
  }
}

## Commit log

2026-09-09 README formatting issues, Rename firmware file
    [CreepyEyes.ino]
2026-09-09 .ino rename in firmware, upload calibration .ino to firmware
2026-09-09 Update firmware README to include calibration.ino
2026-09-24 Latest ino's, build info and stl's
    [creepy-glass-holder.3mf, creepy-glass-holder.stl]
2026-09-24 Add current CreepyEyes BOM and tools
2026-09-24 Add current textual CreepyEyes wiring reference
2026-09-24 Add current compact hardware build guide
2026-09-24 Fix creep calibration labels and wearer orientation
    [CreepyEyes.ino]
2026-09-24 Clarify wearer-perspective calibration orientation
2026-09-24 Fix FESTER and LURCH calibration log labels
    [CreepyEyes.ino]
2026-09-24 Clarify tested ball-bearing linkage clamp
2026-09-25 Creepy Eyes Case 3D print files
    [CreepyEyes-3Slot-Box.3mf, CreepyEyes_3Slot_Box_BASE_70mm.stl, CreepyEyes_3Slot_Box_LID_70mm.stl]
2026-09-25 Document CreepyEyes travel case and build image
2026-09-25 Document printed CreepyEyes travel case
2026-10-18 Document Shoe Goo wire loom attachment
